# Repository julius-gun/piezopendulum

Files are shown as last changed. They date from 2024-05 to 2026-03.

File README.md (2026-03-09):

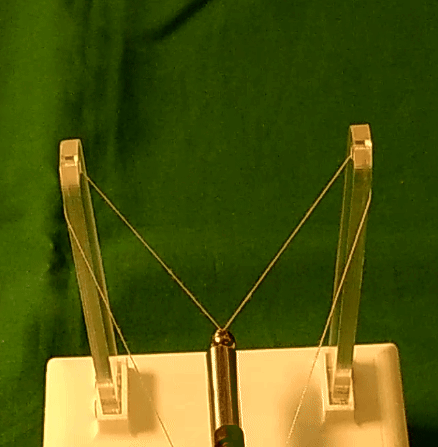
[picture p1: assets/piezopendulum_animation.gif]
[piezo animation]


**[Download the full video](https://github.com/julius-gun/piezopendulum/raw/refs/heads/main/assets/piezopendulum.mp4)**

---

# The Self-Sensing Piezoelectric Pendulum

### Vision: Rescuing a Legacy Demonstrator

This project revitalizes a classic 1993 piezoelectric pendulum, a key educational tool at the Technical University of Munich. The original, while brilliant, was facing obsolescence due to aging electronics and inaccessible Assembler software. The vision was to engineer a modern, robust, and user-friendly successor that preserves its core teaching value for the next generation of engineers.

---

### Watch it in Action

The new demonstrator successfully replicates all key operations of the original, including self-sensing impulse detection, launching a suspended ball, and achieving a precise, bounce-free catch upon its return.

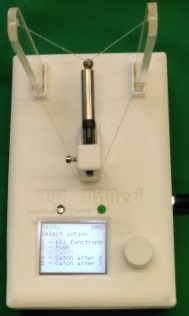
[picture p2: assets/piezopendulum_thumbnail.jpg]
Link to Video on GitHub


---

## Key Contributions & Features

*   **Complete Technological Overhaul:** Replaced 30-year-old electronics and Assembler code with a modern system based on a **Raspberry Pi Pico** and **C++**.
*   **Self-Sensing Actuation:** The piezo actuator itself detects the returning ball's impact, eliminating the need for external sensors.
*   **Precise Bounce-Free Catch:** The system discharges the piezo's energy at the right moment, causing the ball to "stick" to the actuator without bouncing.
*   **Integrated & Robust Design:** A compact, 3D-printed enclosure integrates the actuator and control unit, eliminating fragile external cables.
*   **Intuitive User Interface:** Simple rotary encoder and a clear LCD screen.

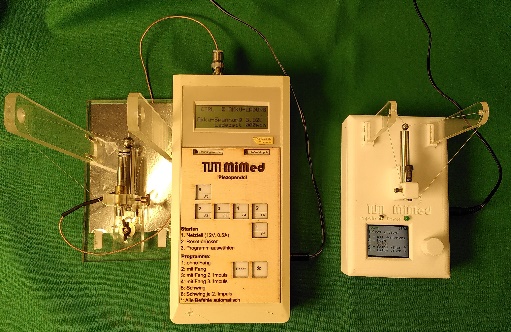
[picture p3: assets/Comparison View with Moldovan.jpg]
Comparison of the old and new pendulums


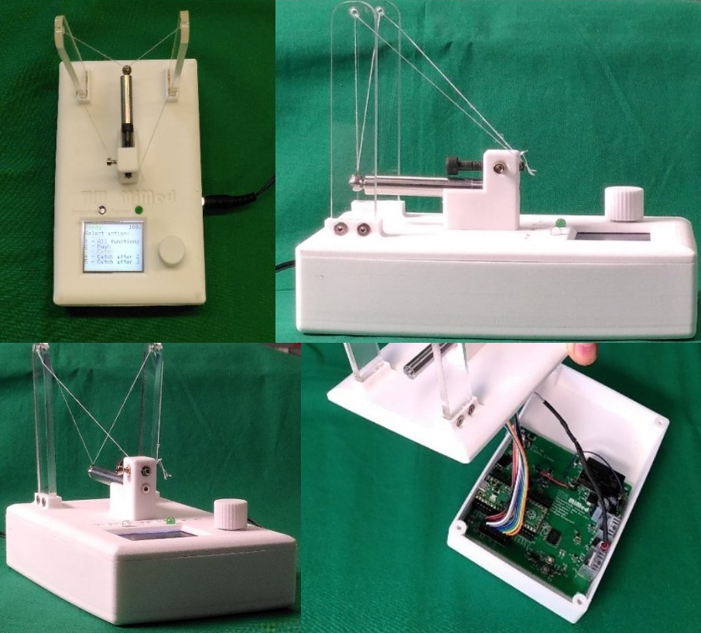
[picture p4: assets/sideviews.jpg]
Side views of the new pendulum


## Technical Breakdown

The project followed a clear modernization path:

1.  **Electronics Redesign:** A custom PCB was designed featuring a half-bridge configuration with fast-switching MOSFETs and a bootstrap gate driver to precisely control the high-voltage piezo actuator.
2.  **Intelligent Control:** A Raspberry Pi Pico runs the C++ firmware, handling user input, display updates, and the critical microsecond-level timing required for the bounce-free catch.
3.  **Physical Redesign:** The enclosure and actuator mount were designed in CAD and 3D printed, allowing for rapid prototyping and a compact, integrated final form.
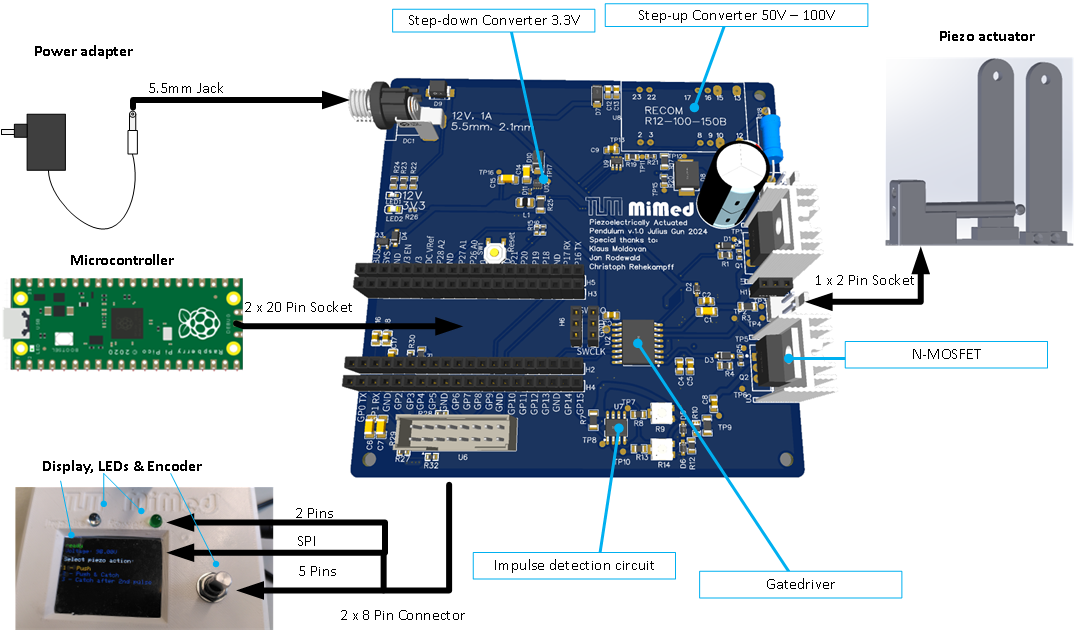
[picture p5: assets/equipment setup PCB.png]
Custom PCB with Raspberry Pi Pico

---

## Read the Full Thesis

For a complete technical deep-dive, including schematics, code, and design evaluation, you can access the full bachelor's thesis.

**[Download the Thesis PDF](self-sensing_piezoelectrically_actuated_pendulum_julius_gun.pdf)**

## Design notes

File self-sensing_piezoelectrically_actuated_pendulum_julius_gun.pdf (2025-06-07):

Technical University of Munich TUM School of Engineering and Design Institute of Micro Technology and Medical Device Technology (MIMED) Prof. Dr. rer. nat. Dipl.-Ing. Tim C. Lüth

Bachelor's Thesis

# Development of a Self-Sensing Piezoelectrically Actuated Pendulum

Julius Gun

Principal Investigator | Univ.-Prof. Dr. Tim C. Lüth Institute of Micro Technology and Medical Device Technology
Supervisor | Jan Rodewald, M. Sc. Institute of Micro Technology and Medical Device Technology
Beginning | 01.11.2023
Submission | 31.05.2024

Abstract

### Abstract

Klaus Moldovan's 1993 piezoelectric pendulum, a key demonstrator at the Technical University of Munich, faced obsolescence from aging electronics and Assembler software. I developed a modern successor, overhauling its technology while preserving its educational core. My goal was a robust, user-friendly demonstrator for engineering students.

My new pendulum retains the original's self-sensing capability. A linear piezoelectric actuator detects an approaching suspended ball without auxiliary sensors, propels it, and achieves a bounce-free catch upon return. This version uses a Raspberry Pi Pico microcontroller programmed in C++, a substantial upgrade.

The electronic redesign incorporates fast-switching MOSFETs with a bootstrap gate driver and a window comparator for impulse detection. I also created a compact, 3D-printed enclosure integrating the piezo actuator onto the control unit. This integration eliminates external cabling, enhancing robustness and aesthetics.

The resulting enhanced pendulum replicates all key operations of Moldovan’s device. A simplified user interface, with a single rotary encoder and push-button, makes the demonstrator intuitive. This project ensures a valuable, hands-on tool continues to teach piezoelectric phenomena effectively.

12 Keywords:

Self-Sensing Piezoelectrically Actuated Pendulum Smart piezoelectric actuator
Piezoelectric pendulum
Smart piezoelectric pendulum
Piezo pendulum
Self-sensing piezo actuator
Demonstrator of the piezoelectric effect and inverse piezoelectric effect Piezoelectric demonstration model
Piezoelectric damping
Piezoelectric feedback control
Actively damped piezoelectric system Piezoelectric actuation pendulum

Forword to Revised Version

### Forword to Revised Version

I have revised my submitted bachelor thesis, removing minor mistakes. I have inserted the updated version of code which has new functionalities and and now is optimized for a 4g ball. I also used Gemini 2.5 Pro Preview 05-06 for paraphrasing of my text so that the active voice is used.

If somebody wants to build a new piezo pendulum, then rather use a piezo actuator with a higher capacitance than the one used in this project and add a shunt resistor in front of it to avoid the resonance frequency (also see 2.6.1.2 Piezo Actuator, and 1.2.1.3 Characteristics of Piezoelectric Materials).

Also redesign the complete case, so that it is easier to open it (right now 4 screws need to be undone). Rather have the piezo connector outside the box and not inside so that an oscilloscope can easily be connected. It could even be desirable to have the piezo actuator mounted on a separate base, just like Moldovan 1993 did, if experiments are to be carried out.

For any questions regarding this pendulum, feel free to contact me.

Julius Gun, 07.06.2025

Acknowledgment

### Acknowledgment

This thesis would not be complete without acknowledging those who offered their expert guidance and support. My profound appreciation goes to Klaus Moldovan, originator of the 1993 piezo pendulum, for his readiness to assist through extensive correspondence, which proved critical to my study. My supervisor, Jan Rodewald, deserves special thanks for his continuous support and valuable counsel throughout this endeavor.
Gratitude is also owed to Dr. Franz Irlinger, who facilitated the acquisition of critical documents and my introduction to Klaus Moldovan. My respectful acknowledgment goes to Prof. Dr. Tim
C. Lüth, whose teachings ignited my fascination with electronics. The collaborative and welcoming environment provided by the team at MIMED has greatly enhanced my research experience. Acknowledgment is due to Christoph Rehekampff for his readiness to assist and his technical guidance with the electronic circuit.
Also, thanks to Andreas Haas from Physical Instruments (PI), Markus Wörl and Florian Schweidler.
Finally, I would like to thank my dear mother, Emma Weiß, for her support throughout all those years. You are wonderful.

Contents

### Contents

1. Introduction

### 1. Introduction

### 1.1 Application

Piezoelectric principles are pivotal in the "Mechatronic Device Technology" and "Microtechnical Sensors and Actuators" lectures at the Technical University of Munich. The piezoelectric demonstrator within this context provides students with an empirical understanding of the conversion of mechanical stress into electric charges and vice versa. Engaging with this demonstrator imparts valuable practical experience and technical knowledge essential for precise applications in advanced engineering sectors.

The application of piezoelectric effects in academic settings helps demonstrate and clarify advanced concepts. This leads to measurable educational outcomes in student engagement and understanding. This demonstrator transforms abstract textbook theories into a concrete example.

The practical deployment of piezoelectric devices spans a range of applications that benefit from high precision and quick responsiveness. Self-sensing piezoelectric ceramics offer an innovative method by combining actuation and sensation. This combination reduces physical dimensions and response time, significantly contributing to space-sensitive and finely tunable technologies.

In the medical field, the non-magnetic nature of piezo actuators is a major asset. These devices play a vital role in MRI scanners by enabling precise adjustments without interfering with the imaging process (Fischer et al., 2011; Wang et al., 2009) . Piezo technology is essential for administering accurate doses in medical pumps, like those for insulin. It is also used in ultrasonic surgical tools and diagnostic devices, such as ultrasonography transducers, where electromagnetic disturbance must be avoided (Li et al., 2009) . Additionally, these actuators facilitate precise fluid control in miniaturized lab-on-a-chip systems used for medical testing.

However, piezo actuators have a higher cost because of their sophisticated technology. They are also limited in their movement range, and their piezoelectric materials can be delicate, risking damage under high stress or if mishandled. Their operation typically requires high-voltage inputs, complicating the design. They are also sensitive to temperature changes, which could affect their functionality. Lastly, they exhibit varying levels of hysteresis and nonlinear behavior (Chopra and Sirohi, 2014, p. 154) . The perception of piezoelectric effects varies depending on the application.

Self-sensing piezoelectric ceramics combine action and sensing in one unit. These materials eliminate the need for separate sensors, offering both cost and space benefits (Muth et al., 1995,
p. 692) . Traditional sensors provide precision but often result in costlier and more cumbersome setups. These setups add excess wiring and demand more component room, as seen with encoders (Liseli et al., 2020, p. 2) . The compact design of self-sensing piezoelectric ceramics proves ideal for miniaturized systems and nano-positioning tasks where space is at a premium (see Liseli et al., 2020 for an overview).

1. Introduction

In some applications, the piezoelectric effect is invisible, while in others, it can be perceived visually, acoustically, or haptically. The piezo effect (a piezo actuator subjected to force generates voltage) is visually evident in the spark of a lighter, where applied pressure creates a visible, abrupt voltage between contacts (APC International, 2024) . Additionally, the inverse effect—a piezo actuator subjected to voltage generates force—is most notably observable in devices like high-precision stages. Here, piezo elements enable movement through the inverse piezoelectric effect. This same principle of voltage generation is used in scientific settings, like producing corona discharges in mass spectrometry (Wang et al., 2015) .

In practical applications, piezoelectric actuators exemplified in the Arburg Freeformer 3D printer's printhead demonstrate controlled, nuanced operations. These piezos produce an audible click as they dispense precise droplet formations at frequencies between 60 and 200 Hz, which is crucial for high-quality 3D printing (Arburg, 2024) .

Energy harvesting represents a silent yet impactful application of piezoelectric materials. Away from the audible clicks in 3D printing, these materials discretely capture electricity from vibrations, such as those from vehicles on roads, by embedding piezoelectric elements beneath the pavement (Kaur, 2016) .

The Technical University of Munich is pioneering piezoelectric energy harvesting, as represented in Figure 1. This prototype, a joint endeavor by Prof. Johann Plank and Prof. Xin Cheng, demonstrates the instant energy yield in Joules from pedestrian movement. Future improvements could lead to powering sensors and LEDs in high-traffic areas like bridges, subway stations, and nightclubs.

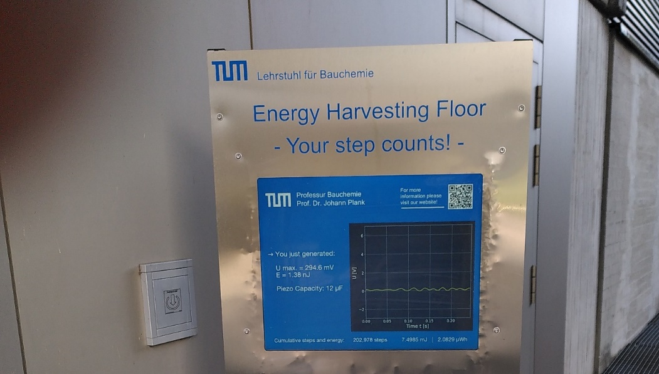
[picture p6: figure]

Figure 1 Energy harvesting floor at the entrance to the Chair for Construction Chemicals, Technical University of Munich.
In Rotterdam, the innovation of piezoelectric energy has been embraced in a dance club, which features a 38m²
area lined with piezoelectric tiles. This novel implementation results in a noteworthy 30% reduction in energy consumption, although the initial investment stood at $257,000 (Moussa et al., 2022, p. 4) .

1. Introduction

The bulk of this expenditure is often on the piezoceramic material, which in many cases consists of lead zirconate titanate (PZT). With ongoing research, more cost-effective lead-free piezoceramics may emerge on the market (Shrout and Zhang, 2007) . Seyfert et al., 2021 from the Technical University of Munich researched the use of piezoelectric PVDF film and its potential for energy harvesting. This study demonstrates the film's applicability in capturing energy from environmental mechanical forces.

Having reviewed some applications of piezoceramics, the next section examines the current state-of-the-art piezoelectric pendulum after some definitions.

### 1.2 State of the Art

This section delineates the current advancements in self-sensing piezoelectrically actuated pendulums. Piezoelectric devices operate through two fundamental mechanisms: the direct effect, where applied force is transformed into voltage detectable by specialized electronics, and the inverse effect, which involves expansion upon voltage application. Understanding these underlying principles is critical before discussing the current state-of-the-art piezoelectric pendulum.

The reader is assumed to have a foundational understanding of electronic concepts and formulae. Should further clarification or in-depth exploration be necessary, standard electronic textbooks are recommended as reference materials. Notable examples include the works of Tietze et al., 2016 and Horowitz and Hill, 2015 , which serve as comprehensive resources in the field.

### 1.2.1 Definition of Terms

The discovery of piezoelectric materials is attributed to French physicists Jacques and Pierre Curie in 1880. They unveiled the property of specific crystalline structures, like quartz, to generate an electric charge under mechanical stress. This bidirectional conversion capability between mechanical and electrical energies marks the cornerstone of piezoelectricity. The etymology of "piezoelectricity" is rooted in the Greek term 'piezein,' which translates to press, describing the materials' electric reaction to pressure.

### 1.2.1.1 The Piezoelectric Effect

When piezoelectric materials are subjected to stress, they produce a voltage. This is known as the piezoelectric effect. It is observed when a piezoelectric actuator, subjected to force F [N], generates voltage V [V], captured by equation (1). This shows how a piezoelectric actuator converts mechanical pressure (force per area) into an electrical signal (voltage). This is crucial for the device’s ability to detect a ball without other sensors, as I will discuss later.

V =

d33∗F
C

=

Q
C

(1)

V | Voltage | [V]
d33 | Piezoelectric module [m/V]
F | Force | [N]
C | Capacitance | [F]
Q | Electrical charge | [C]

1. Introduction

Here, the constant d33 [m/V] represents the longitudinal effect - the piezoelectric charge constant along the polarization axis of the piezoelectric material, while Q [C] is the electrical charge produced, C [F] is the capacitance of the piezoelectric material. My discussion focuses on a onedimensional scenario, considering the linear relationship between the force applied along the piezoelectric disc's polarization direction and the resulting electrical output.

The elongation ∆l/l in one dimension is proportional to the longitudinal effect d33 along the polarization axis of the piezoelectric material, see equation (2). This is important because it mathematically expresses the direct proportionality between the mechanical stress σ(which is force per area) experienced by the device and the electric field/response ε. This relationship further underpins the actuator's ability to convert electrical signals into mechanical pressure. Thus, a force of a ball on an actuator produces an electrical signal and vice versa, validating the piezoelectric behaviour explored in this research.

∆l
l

=

σ∗1
E

+d33∗ε

(2)

∆l/l | elongation | [-]
σ | Mechanical stress | [N/m² ]
E | Young's modulus | [N/m² ]
d33 | Piezoelectric module [m/V]
ε | Electric field | [V/m]

### 1.2.1.2 Inverse Piezoelectric Effect

Conversely, when a voltage is introduced to the piezoelectric material, its shape alters by extending in length ∆l. This is called the inverse piezoelectric effect.

### 1.2.1.3 Characteristics of Piezoelectric Materials

When examining piezoceramics, it is critical to understand that the absorbable and releasable energy Wa, measured in joules (J), is calculated by formula:

W a=

1
2

∗Cp

∗V p

2

(3)

The capacitance and voltage range determine the energy a piezo can absorb and release; therefore, this is an important consideration when selecting a piezo actuator. Most notably, the energy quadruples when the voltage Vp is doubled.

Characterizing the piezoelectric device electrostatically, one can conceptualize it as a capacitive entity. The capacitance Cp [F] of such a device is quantitatively defined by equation (4),

Cp=

ε0∗εr∗A∗n
h

=

ε0∗εr∗π∗r

2∗n
h

(4)

1. Introduction

where ε0 is the electrostatic constant, εr
is the relative permittivity of the piezoelectric material, A is the area of the individual ceramic disc, r is the radius of the disc, n denotes the total number of piezoelectric ceramic discs in the stack, and h is the distance between the piezoceramic discs. From equations (3) and (4) it follows that the absorbable energy is proportional to the capacitance Cp. Notably, the capacitance is directly proportional to the square of the actuator's radius and to the number of discs, which accounts for the actuator's dimensional properties – width and length, respectively.

The function of the piezoelectric pendulum, which uses a linear piezo actuator, is the focus of my investigation. Figure 2 portrays the process of energizing the piezoelectric material by applying voltage through wires, resulting in its expansion by a length of ∆l; the material contracts to its original size upon removal of the voltage. In the depiction, the left side shows the connection to the voltage source and the grounding at the other end. Typically, the piezoelectric stack is composed of numerous layers of ceramic, often using a material known as lead zirconate titanate (PZT).

Figure 2 Structure and contacting of a stacked piezo actuator (Image used with kind permission from PI Ceramic GmbH, available at https://www.piceramic.com/en/expertise/piezo-technology/properties-piezo-actuators/electricaloperation (https://www.piceramic.com/en/expertise/piezo-technology/properties-piezo-actuators/electrical-operation) [Accessed 14 May 2024])

Figure 3 shows a sectional view of a linear piezo actuator. Its multilayered structure increases its capacitance according to equation (4). A hardened tip prevents damage to the actuator's head. For secure attachment, the mounting plate has a thread to enable screwing it into position.

Figure 3 Linear piezoelectric actuator in cut view. The ball hits the hardened head on the right side. (Image used with kind permission from Klaus Moldovan (Muth et al., 1995, p. 699) )

1. Introduction

As depicted in Figure 4, the piezo actuator's behavior can be likened to that of a capacitor (Cp). It is critical to recognize that the piezo and parasitic resistance form a low-pass filter, with a cutoff frequency fp given by equation 5:

f

p=

1
2 π RpCp

(5)

Figure 4 Schematic of parasitic resistance and capacitance of piezo actuator, forming a low-pass filter.
A design must consider the piezoelectric actuator's capacitance and the parasitic resistance. In a numerical simulation of a piezo ceramic at impact by a steel ball by Schweidler, 2004, p. 42 , post-impact oscillations of the piezoceramic endure for approximately 5ms. This phenomenon is visually represented in Figure 5, capturing the attenuated response past the moment of impact. The actuator is vibrating, as it is subjected to both tensile and compressive stress in a fastreciprocating manner.

The frequency with which the piezo oscillates in this process is dependent on equation (5). It would be desirable to have a cutoff frequency f3db

1
from below the resonance frequency to avoid destroying the piezo. Otherwise, it could oscillate so severely at its resonance frequency that the many layers of glued piezoceramic would separate (Moldovan, 1994a, p. 22) , effectively destroying the device. Achieving a cutoff frequency below the resonance frequency can be done by using a piezo with a high capacitance Cpor by increasing Rp, for example, by adding a resistor in series with the piezo.

1
The cutoff frequency f3db is the point of a filter where the attenuation of the signal is reduced to 0.707 times the maximum gain.

1. Introduction

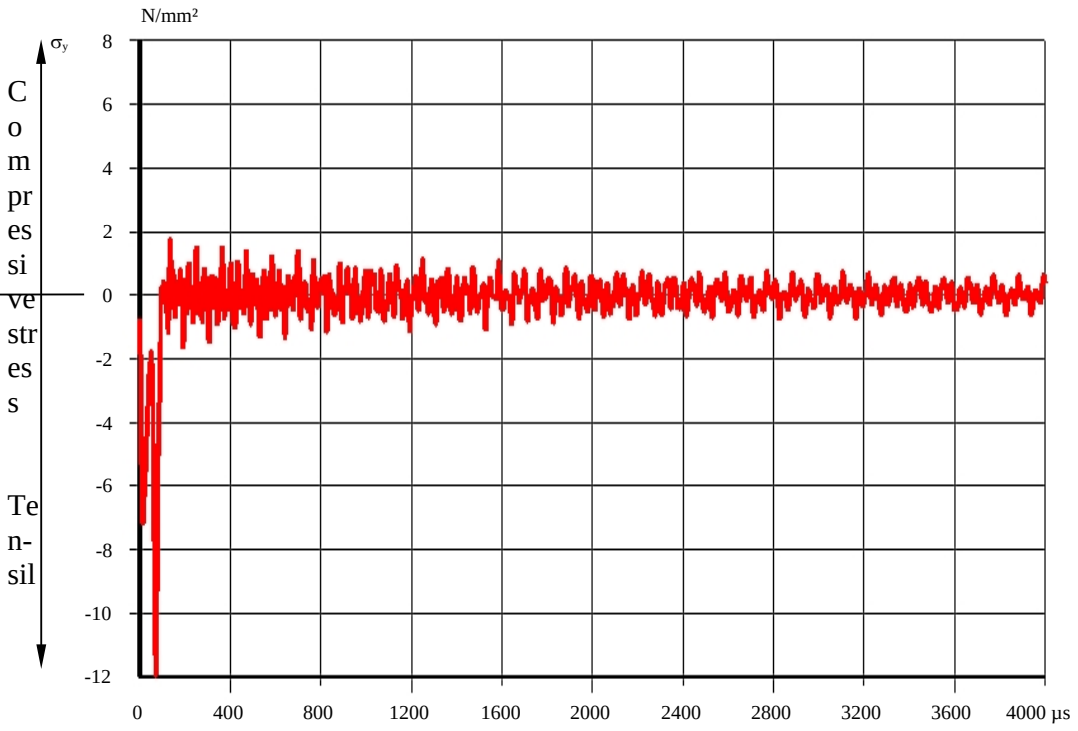
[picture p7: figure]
N/mm²; C o m pr es si ve str es s; Te n- sil

Figure 5 Simulated stress of the piezo actuator on in contact with a ball in the axial direction (Image used with kind permission from Florian Schweidler (Schweidler, 2004, p. 42))

The voltage across the piezo is:

V p=Rp

∗I

(6)

where Rp is the parasitic resistance before the piezo and I is the current across it.

The dynamic voltage at charging of the piezo V p

(t) when charging the piezo is given by equation (7), and when discharging by equation (8), where t represents the time. Figure 6 shows a plot with exemplary values. This resemblance to capacitor voltage characteristics is expected because the piezoelectric device has its own capacitance, as per equation (4). Upon activation, the piezoelectric device's voltage rises to a peak value V, and upon deactivation, it decreases back to 0 volts.

V p

(t)=V∗e

−t
Rp∗Cp

(7)

V p

(t)=V∗(1−e
−t

Rp∗Cp )

(8)

1. Introduction

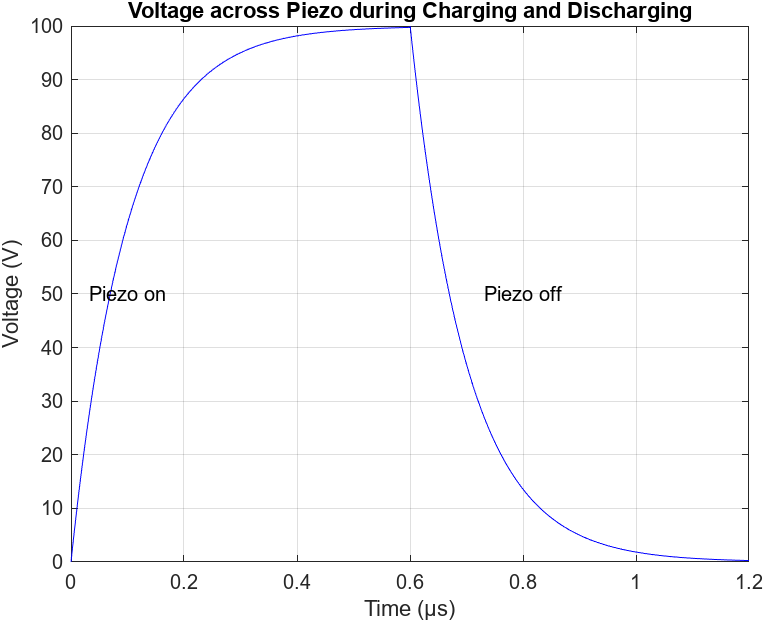
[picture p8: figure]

Figure 6 Voltage across piezo during charging and discharging with exemplary values.

### 1.2.1.4 Test Setup

Figure 7 shows a schematic of the demonstrator's test setup, consisting of a piezo actuator and pendulum. A ball with a mass mb is suspended by a string from above. Gravity is signified by g (9.81 m/s²
), h is the height, and φ is the angle at which the ball is at the moment. When the piezo is turned on, it charges. Consequently, electrical energy (equation (3)) is turned into kinetic energy (equation (9)). The ball is shot away with a velocity vb and flies to a certain height, h. There, the potential energy is at a maximum, as denoted in equation (10).

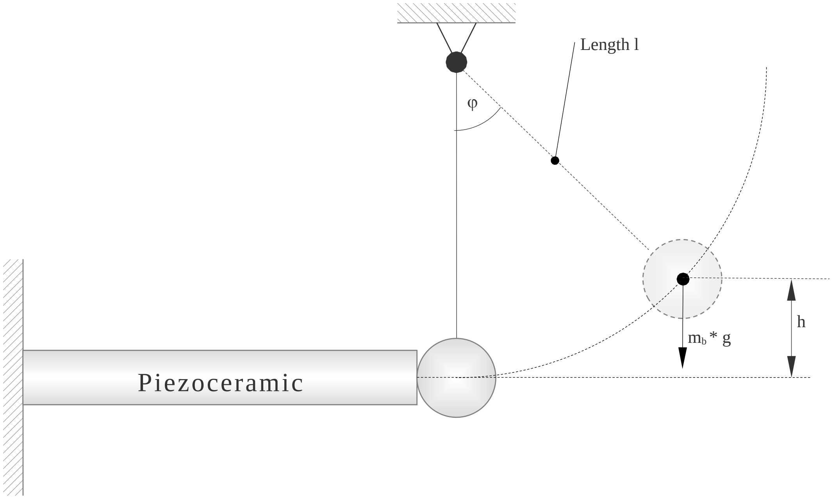
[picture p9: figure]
Length l; Piezoceramic

Figure 7 Schematic of piezo actuator and pendulum (Image used with kind permission from Florian Schweidler (Schweidler, 2004, p. 23))

At the lowest point (h = 0m) the kinetic energy Ek
is highest and is given by equation (9). Ek=

1
2

∗mb∗vb

2 | (9)

The potential energy Ep is is given by equation 10.:

1. Introduction
Ep=mb∗g∗h | (10)
In an ideal setting, Ep equals according to energy conservation principles, and so the resulting velocity vb is given by:
vb=√2∗g∗h | (11)

This equation allows calculation of the ball's velocity at its lowest point, just before contacting the actuator, simply by knowing the height to which it was shot. In this ideal setting, the velocity with which the ball is shot is approximately the same as the final velocity when it hits the piezo again. The consistency in initial and return velocities is essential for determining the correct delay for discharging the piezo's stored energy. This allows for a bounce-free catch of the ball, which I will discuss in the next section.

### 1.2.1.5 Bounce-free Catching of a Ball

For the ball to adhere instantly, the actuator must absorb all the collision's energy. As the ball hits the expanded ceramic material, it applies a compressive force, altering the electrical charge and causing a detectable voltage shift. The electronics of the system then release the energy from the ceramic at the precise moment to ensure the ball remains in place (Muth et al., 1995,
p. 692) . Because the initial velocity is approximately the same as the final velocity when the ball returns, only the correct time delay to discharge the piezo needs to be found.

Figure 8 shows the force-time curve of a ball on impact with the piezo pendulum with exemplary values (Schweidler, 2004, p. 12) . The sketches above the curve show the position of the ball at each point in time. Fb(t) represents the curve of the force of the ball over time. At t1 the ball hits the piezo and starts to compress. Then the force rises until it reaches its maximum force Fmax at t2 when the ball is in the most compressed state. After this, the force falls again, reaching the bottom end at t3 when the ball leaves the actuator again and flies off (this is not

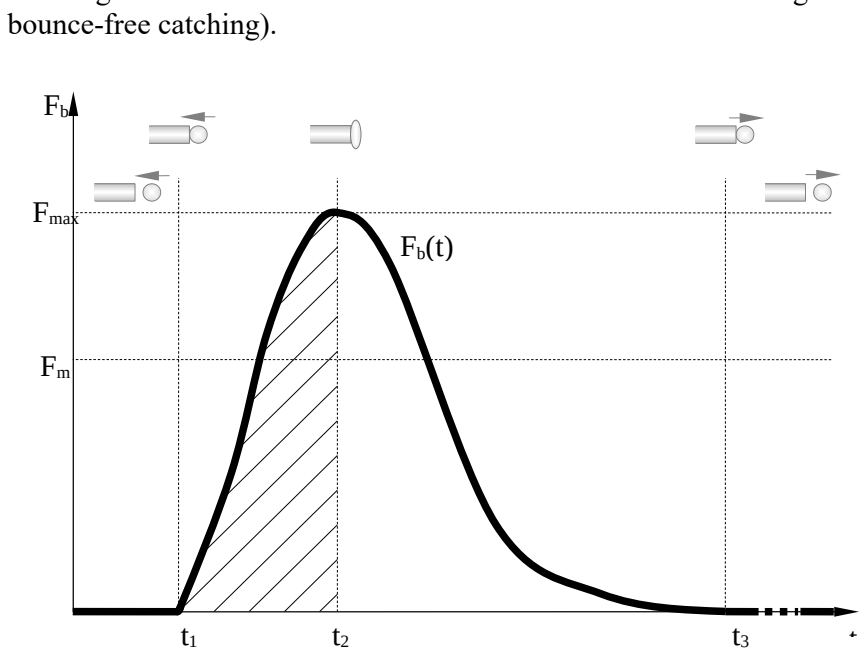
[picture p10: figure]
bounce-free catching).; Fmax

Figure 8 The characteristic curve of the force Fb during the first contact of the ball with the piezoceramic. The sketches above the curve show the position of the ball at each point in time. (Image used with kind permission from Florian Schweidler (Schweidler, 2004, p. 12))

1. Introduction

The average force Fm [N] over the impact duration is equal to:

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
Fb∗dt=

1
t

2−t
1

( p2−p1)

(12)

The momentum p [N/s]is defined as:

p=mb∗vb

(13)

The impulse ∆ p[N * s], the change in an object's momentum when a force is applied over time, is the area under the curve in Figure 8 and is given by the following equation:

∆ p=p2−p1=mb∗( v2−v1

)

(14)

When the piezoelectric actuator in the demonstrator detects the incoming ball, its task is to generate enough counter-impulse to stop the ball, effectively making the final momentum of the ball zero and, therefore, preventing it from bouncing off. The piezoelectric actuator must produce a force for a specific duration to create a counter-impulse equal and opposite to the ball's momentum. It achieves this by discharging the piezo at the correct moment. This effect permits a ball to "stick" to the actuator upon impact without bouncing back, as noted by Muth et al., 1995, p. 692 . It gives the illusion that the ball is magnetically attached to the actuator.

The timing of this force is critical - if released too late or too early, the desired effect of "sticking" will not be achieved. This delay time can be determined experimentally. Alternatively, a sophisticated algorithm could be developed. Accurate timing for a bounce-free catch may be determined through real-time voltage monitoring at the point of contact. This requires a calculation that accounts for initial voltage, ball mass, electronic response time, and the piezoelectric material's delay properties.

### 1.2.2 The Piezo Pendulum Engineered by Klaus Moldovan

Currently, the piezo pendulum developed by Klaus Moldovan in 1993 at the Technical University of Munich represents the state of the art for academic demonstrations (Moldovan, 1993) . No other similar piezo pendulum demonstrator is known to the author. Figure 9 depicts the design of Moldovan's device: A ball is attached to a string (1) so that the tip of the piezo actuator (2) touches it when the ball is at its lowest point. The piezo is screwed to a piezo holder (3), which itself is connected to the piezo base (4). Cable connection (5) to the control unit permit the piezo to be energized. The control unit, incl. display (6) and buttons (7), enable the user to choose functions. Extensive documentation of the pendulum by Moldovan allows for an in-depth understanding of the system (Moldovan, 1994a, 1994b, 1994c) .

1. Introduction

Figure 9 Representation of the piezo pendulum engineered by Klaus Moldovan. Ball on a string (1), piezo actuator (2), piezo holder (3), piezo base (4), cable connection to the control unit (5), control unit incl. display (6) and buttons (7)
Figure 10 a) shows a photo of the pendulum developed by Moldovan. A wooden panel was added later for simplicity. The control unit without the wooden panel is shown in Figure 10 b). There are 16 buttons to operate the unit.

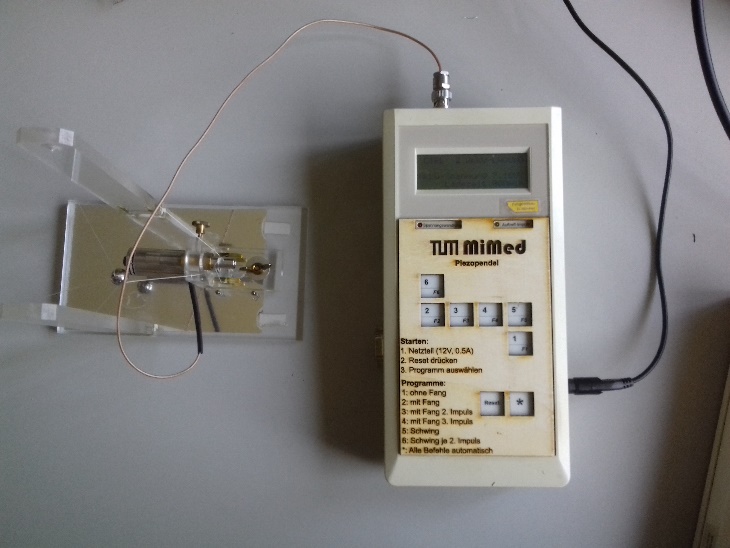
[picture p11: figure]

a) b)

Control Unit

Figure 11 and Figure 12 provide insight into the innovative use of power electronics. Moldovan’s choice to implement a flyback converter for piezo voltage management and two forward converters for controlling the two Metal Oxide Field Effect Transistors (MOSFETs)—a type of switch—is of particular interest. These three transformers were custom-made for this purpose (Moldovan, 1993, pp. 29–34) . This level of craftsmanship underscores the customdesigned nature of the pendulum's electronic system. Additionally, the incorporation of a rechargeable battery alongside the 12V power supply enhanced the device's portability.

Figure 10 a) Piezo pendulum engineered by Klaus Moldovan with later wooden panel modification Right: Control of the piezo pendulum engineered by Klaus Moldovan without wooden panel

1. Introduction

A full explanation of the symbols displayed and terms being used can be found in the referenced materials or standard electronic textbooks, such as those provided by Tietze et al., 2016 and Horowitz and Hill, 2015 .

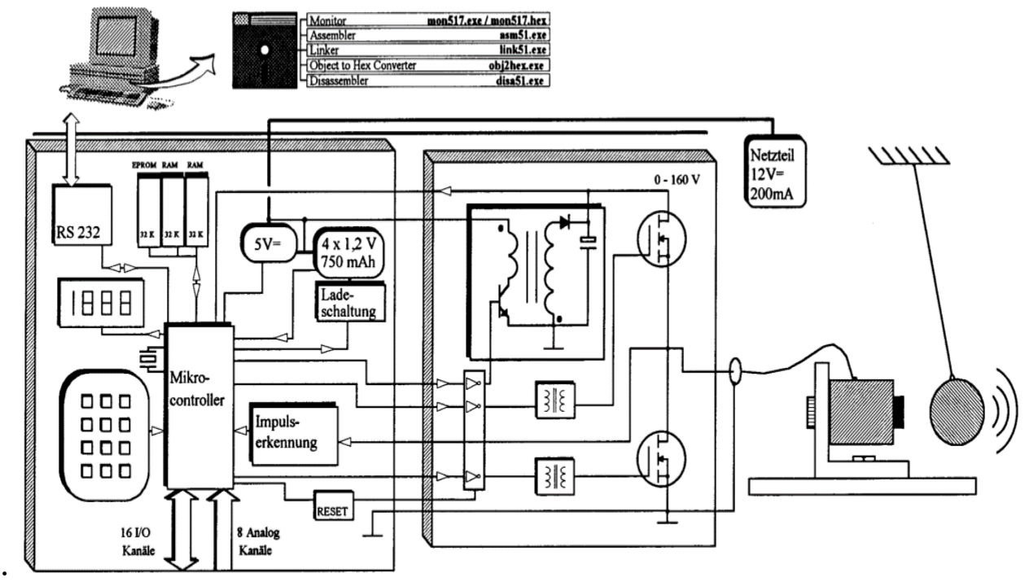
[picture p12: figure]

Figure 11 Basic view of the parts in the piezo pendulum engineered by Klaus Moldovan (Image used with kind permission from Klaus Moldovan (Moldovan, 1993, p. 8) )
Figure 12 offers a more detailed view of the hardware configuration within the piezo pendulum engineered by Klaus Moldovan. Notably, Moldovan's design incorporates two MOSFETs connected in parallel.This connection increases the maximum current the piezo receives. He also implemented a hardware oscillator and counter circuit crucial for controlling operational delay times. This configuration ensures exact timing for the pendulum ball's launch and capture, which is pivotal for system accuracy, as discussed in section 1.2.1.5. Such precision enables timing adjustments to within 55.6 nanoseconds (Moldovan, 1994a, p. 9) .

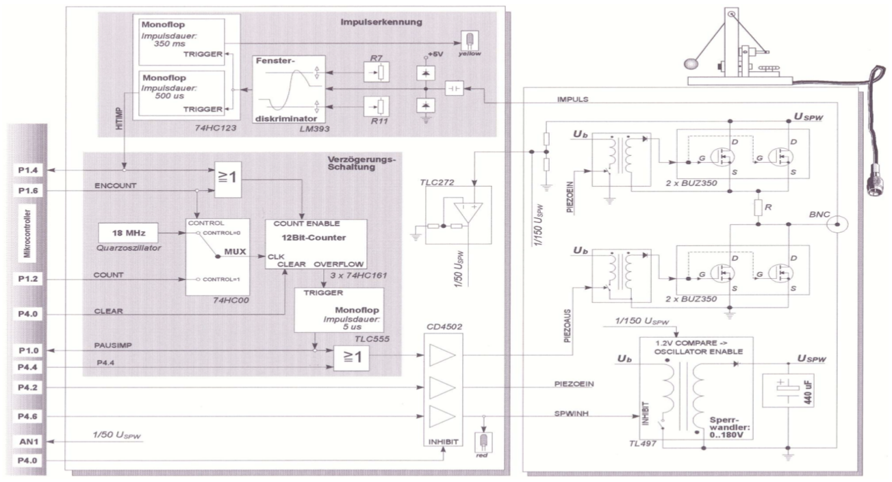
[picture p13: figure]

Figure 12 Hardware structure of the piezo pendulum engineered by Klaus Moldovan (Image used with kind permission from Klaus Moldovan (Moldovan, 1994a, p. 3) )

1. Introduction

Functions of the Control Unit of Moldovan
The control unit's functions, listed from 1 to 7, illustrate the system’s versatility. The system was carefully designed to store parameters in an electrically erasable programmable read-only memory (EEPROM).

The functions of the control unit are:

1. Shoot: Launches the pendulum ball.
2. Shoot and Catch after First Impulse: Catches the ball as it returns.
3. Shoot and Catch after Second Impulse: Captures the ball after a second impulse.
4. Shoot and Catch after Third Impulse: Secures the ball post-third impulse.
5. Resonance: Propels the ball upon immediate impulse detection.
6. Resonance after Second Impulse: Projects the ball after the second impulse is detected.
7. All Functions: Cycles through all modes sequentially.

Also, there is a mode of simultaneous operation. When linked via RS232, two control units can operate two pendulums in alternation.

A helper function in the pendulum assists in finding optimal delays, as shown in Figure 13. The correct delay for discharging the piezo is very important for a bounce-free catch, as discussed in the section 1.2.1.4. Each catch mode necessitates specific delays; voltage changes require delay recalibration for all functions, and this helper function speeds up the process. The ball is shot periodically in this mode. The delay time to discharge the piezo is incremented or decremented in steps according to the user input. It is not fully automatic; it needs operator confirmation of ball catch but refines delays in steps to enhance performance.

Figure 13 Automatic time delay configuration of the piezo pendulum engineered by Klaus Moldovan (Image used with kind permission from Klaus Moldovan (Moldovan, 1994a, p. 11) )
The remarkable durability of Klaus Moldovan’s pendulum, with an operational lifespan of 30 years, can likely be attributed to the strategic incorporation of high-quality digital components. Analog components, which are often more susceptible to inaccuracies, were judiciously employed only when absolutely essential.

1. Introduction

### 1.2.3 Research about Piezoelectricity

Having examined the state-of-the-art pedagogic demonstrator, attention now turns to contemporary research in piezoelectricity and the concept of self-sensing actuators powered by piezoelectricity. A self-sensing piezo device uses piezoelectric ceramics for both actuation and detection. This eliminates the need for an external sensor to determine, for example, position (Dosch et al., 1992, p. 167) . Expanding the knowledge on piezoelectric materials, Dosch et al., 1992 showcased that a piezoelectric element could simultaneously serve as an actuator and sensor. They proposed this method as an efficient vibration damping mechanism in a cantilever beam. This integration reportedly decreased the system's stabilization time by a factor of ten compared to systems not using piezoelectric technology.

In another study, it was shown that it is possible to recover the energy stored in a linear piezo actuator during the discharge phase and, with this, to estimate the piezo position with an error of less than 5% (Chiaberge et al., 2009, p. 8) . The system was developed for fuel injection in the cylinder combustion chamber.

Despite their typically limited range of motion, piezo actuators' displacement can be significantly augmented through the application of elevated voltages or lever amplification mechanisms. Li et al., 2024, p. 55 reported achieving a 558.3 µm displacement using a lever mechanism at 150V, although the resulting motion exhibits nonlinearity. To address this, the researchers devised a control algorithm tailored to the multistage amplifying mechanism's complex hysteresis behaviour.

At the Technical University of Munich, significant research on piezoelectric ceramics has been carried out within the Institute of Microtechnology and Medical Device Technology (MIMED), as well as its predecessor, the Institute of Microfabrication Technology.

For example, in the realm of printing technology, Rumschoettel et al. crafted a predictive model for a piezoelectric drop-on-demand (DoD) printhead (Rumschoettel et al., 2014; Rumschoettel et al., 2015) . Their model forecasts key droplet attributes, facilitating swifter printing speeds and enhanced precision in droplet placement. Furthermore, Kagerer developed a piezo inkjet drop-on-demand experimentation platform manufactured with rapid prototyping techniques. (Kagerer et al., 2012) . He further showed a cheap and fast way to make unique models of piezoelectrically operated microdroplet generators (Kagerer et al., 2012; Kagerer, 2016) .

1. Introduction

### 1.2.4 Research about Piezoelectrically Actuated Pendulums

Heider, 1976 , demonstrated the effective use of piezoceramics in dot matrix printers. His research focused on the capture process of a rapidly activated print element. Heider's work on dot matrix printers is a foundational study of piezoceramics handling fast, successive impacts. This process parallels the ball being stopped without rebounding in the model I developed. For visual reference, Figure 14 shows one of Heider's experimental setups Figure 14 (Heider, 1976,
p. 15) , which resembles my demonstrator's setup shown in Figure 7.

Figure 14 Experimental setup of the piezo pendulum according to Heider (Heider, 1976, p. 15) (Image used with kind permission from Florian Schweidler (Schweidler, 2004, p. 5) ).
To validate the findings by Heider, 1976 , Florian Schweidler (2004) conducted numerical simulations to analyze stress within a piezoceramic pendulum, using the finite element method (FEM). Through ANSYS, a software dedicated to engineering simulations, he mapped the pressure wave propagation within the piezoceramic upon collision with a steel ball. Figure 15 in his publication presents a three-dimensional model depicting the sizes of a piezoceramic (left) and a steel ball (right) during impact.

Figure 15 Three-dimensional representation of piezoceramic(left) and steel ball (right) in the correct size ratio (Image used with kind permission from Florian Schweidler (Schweidler, 2004, p. 28) )
Figure 16 displays one of Schweidler’s simulation that captures the stress experienced by the piezoceramic at the moment of impact with the steel ball. At this instant, the compressive stress peaks at the piezoceramic's free end, located on the right side (illustrated in red).

Figure 16 Two-dimensional representation of stress in the piezoceramic at impact of steel ball. The compressive stress at the free end (right) reaches its first maximum. The ball is (approximately) stationary in this moment. (Image used with kind permission from Florian Schweidler (Schweidler, 2004, p. 32) )
The stress curves observed from Schweidler's analysis show a considerable match with the experimental stress curves Heider demonstrated in 1976 . This comparison offers a comprehensive examination of the stress response in a piezoceramic subjected to impact by a steel ball. The congruence between the simulated stress distribution and Heider's data strengthens the understanding of the piezoelectric effect in dynamic situations. Together, the analyses affirm the foundational design concepts of the device and underscore the viability of piezoelectric applications in practical settings.

1. Introduction

Muth et al., 1995 further used the same experimental setup in Figure 7 to to evaluate the ball’s velocity in correlation with its mass(Figure 17 a)). They deduced the velocity from the highest point of the ball's post-launch trajectory, using equation (11). Measuring the electrical energy, they calculated the electromechanical efficiency as a function of the steel ball mass (Figure 17 b)). Most notably, the most efficient ball in their setup weighs approximately 24g, achieving a small electromechanical efficiency of 4.8%, while a 3g ball had an efficiency of 1.8%. Leveraging insights into bounce-free catching of the ball, the researchers explored the use of piezo actuators in active damping within optical scanners (Muth et al., 1995, p. 701) .

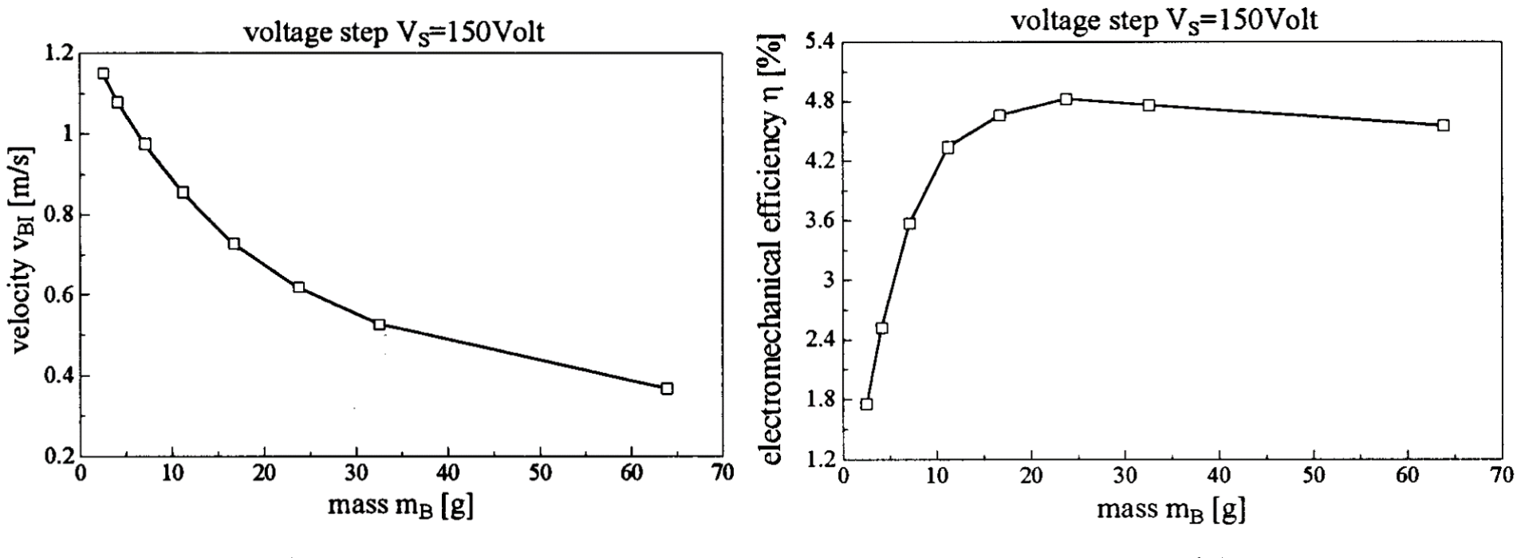
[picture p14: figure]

a) b)
Figure 17 a) Velocity vBI of the steel ball as a function of its mass mB (Image used with kind permission from Klaus Moldovan (Muth et al., 1995, p. 698) ); b) Electromechanical efficiency η as a function of the steel ball mass mB (Image used with kind permission from Klaus Moldovan (Muth et al., 1995, p. 698) )

### 1.3 Disadvantages of the State of the Art

With three decades of service, the pendulum is approaching the end of its operational lifespan. Given its age, mechanical and electrical malfunctions are increasingly likely. Future repairs may be challenging because of obsolete parts or design complexity. Moreover, the existing apparatus presents logistical challenges: As illustrated in Figure 9, the piezo actuator (2) is connected to the controller (6) via a cable (5), creating a vulnerability. This design leaves the system at risk of cable damage, which could easily occur through accidental mishandling or neglect.

The original documentation for the pendulum was misplaced for a period, presenting a hurdle for new operators unfamiliar with the system. To mitigate this challenge, a wooden panel was added to the control unit. Illustrated in Figure 10 a), this panel distinctly identifies each button and provides direct instructions, improving user navigation and simplifying the operation process. Nonetheless, users must manually initiate the reset button upon system startup, a step that persists despite enhancements.

Additionally, the software for Klaus Moldovan's piezo pendulum was written in Assembler—a common choice in 1993 because few programming languages were available for microcontroller development. While Assembler is a fast-executing language, its low-level nature, akin to machine code, renders code modifications quite challenging when compared to more contemporary languages. The software development was not only complex and time-consuming but also demanded specialized expertise. Each alteration required opening the device, physically removing the EPROM chip, and reprogramming it with an EPROM programmer. This labor-intensive procedure added a layer of difficulty to maintaining and updating the pendulum's functionalities.

1. Introduction

Besides the difficulty of changing the software, future failures are possible, and repairs would be complicated.

Figure 18 reveals the interior of the piezo pendulum engineered by Klaus Moldovan. While many components are socketed for easy replacement, a significant obstacle exists: the discontinuation of certain components. For example, the Infineon BUZ350 MOSFET, integral to the device, is no longer in production, complicating maintenance and potentially rendering future repairs infeasible or at best, problematic. Contemporary components may share the same form factor, and with diligent searching, suitable replacements might be found. However, this does not guarantee ease of repair given the obsolescence of these essential parts.

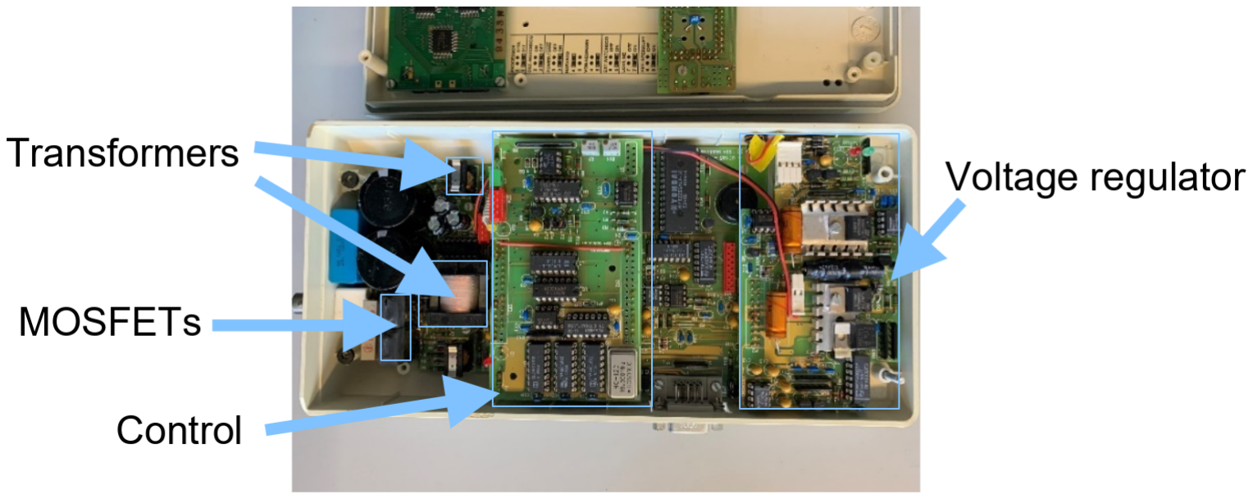
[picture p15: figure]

Figure 18 Piezo control of Moldovan from the inside

2. Methodology

### 2. Methodology

### 2.1 Problem Definition

In this thesis, I aim to create an improved piezoelectric pendulum for educational demonstrations at Munich's Technical University, particularly for courses on Mechatronic Device Technology and Microtechnical Sensors and Actuators. The objective is to upgrade the pendulum's electronics and replace Assembler with a user-friendly programming language, without losing essential features. Additionally, the project intends to simplify the operational process by reducing the number of steps required for activation of functions. Finally, I will evaluate whether the new design maintains the foundational features of Klaus Moldovan's piezo pendulum.

### 2.2 Expected Advantages and Functions of the Solution

Modern programming languages like C++ or Python, with their more accessible syntax and rich libraries, are expected to offer significant benefits in the development and maintenance of the pendulum system, ensuring its longevity and adaptability. Adopting such languages for programming the pendulum system would also allow for more agile responses to changes and potential issues, because the software is easier to update.

Interaction with this demonstrator will afford students practical insight. Their academic growth will intersect with the application of piezoelectricity in precision engineering, medical technology, and microsystems. The adoption of this application-oriented educational method enhances the learning experience significantly. It also imparts crucial skills, preparing students to emerge as visionary engineers, innovators, and inventors in the ever-evolving domains of mechatronics and microtechnology.

The pendulum's upgraded design aims for enhanced usability, functionality, and simple maintenance. It also supports long-term financial viability by reducing the need for specialized expertise or equipment for upkeep.

### 2.3 Structure of the Solution

Figure 19 a) shows a basic diagram of my novel pendulum system, capturing its essential innovation. It serves as an initial visual representation of how the actuator interacts with the controller. A ball is suspended from a cord (1), and a piezo actuator (2) is capable of rapidly launching and catching the ball. This actuator is mounted on a holder (3) and its cable is invisibly connected to the control unit (4). This design leaves the system not at risk of cable damage, which could easily occur through accidental mishandling or neglect. Finally, an LCD display (5) informs the user with relevant data, e.g. of the available functions, and a push-button encoder (6) allows user interaction.

The GUI uses a minimalist design, promoting an intuitive interface with a single encoder and a pushbutton. Such a configuration streamlines interaction by focusing on simplicity and mitigating potential confusion from excess controls. The user-friendly design follows Norman's (2013) principles, advocating for simplicity, reduced cognitive load, and easily reachable functions. Such adherence ensures efficient, precise interaction without requiring extensive guidance.

The GUI forgoes an On-switch, activating instantly with power cord connection. Functions are readily accessible, with navigation via encoder and selection using the button, prioritizing straightforward operation. Figure 19 b) provides a basic visual of the menu. A green text display indicates the device is ready. The voltage is shown in blue on the right.

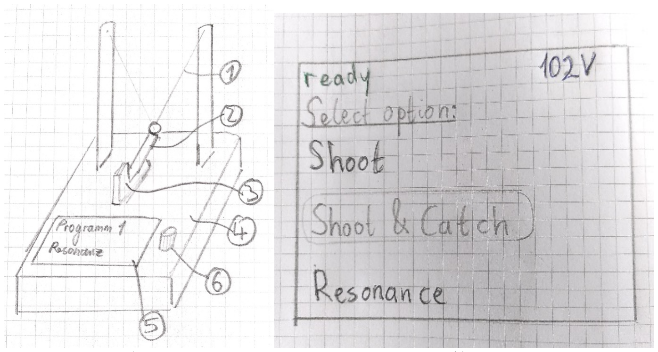
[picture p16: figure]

a) b)
Figure 19 a) Concept of new pendulum. Ball on string (1), piezo actuator (2), piezo holder (3), piezo control unit(4), LCD display (5), encoder with push-functionality (6); b)Basic structure of the GUI

### 2.4 Process of the Solution

Figure 20 clarifies the interaction between the control unit, the actuator, and sensors. The control unit uses the piezo as both a sensor and an actuator. The process involves the interaction with the ball. When the control unit charges the piezo, the ball is pushed away or caught. This is the piezo acting as an actuator. Once a returning ball touches the piezo, it alters its electric charge and causes a voltage shift, which is then detected by the control unit. Users can view data and system commands on a display and manipulate the system by selecting options via an encoder with inherent push capability.

Figure 20 Structure of communication between control unit and the actuator and sensors
Figure 21 presents a streamlined flowchart detailing user interactions within the menu framework. Upon device initialization, a menu with multiple selections appears. A user's choice dictates the program's subsequent operation, including options such as "Play all functions," "Push," "Push and Catch after n Bounces" (with n being 1, 2, or 3), and "Resonance after n bounces." After completing a selected activity, the user can choose another operation; however, this subsequent selection process is not depicted because of spatial constraints.

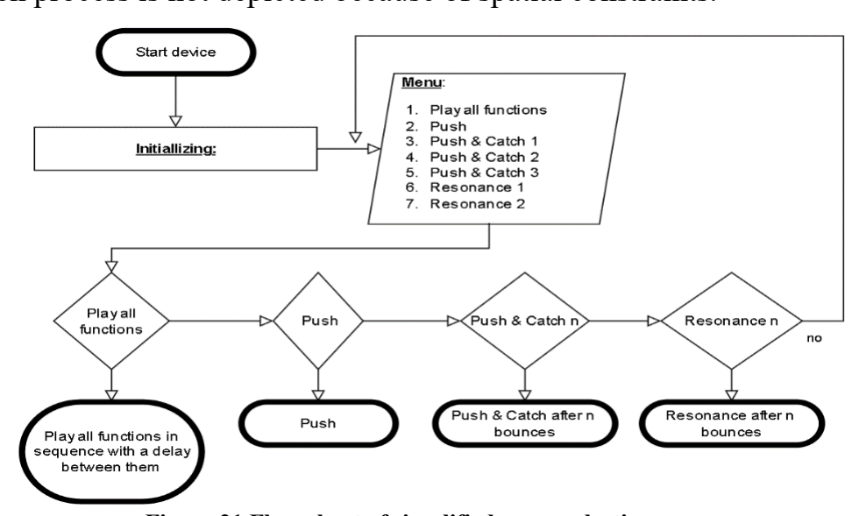
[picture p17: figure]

Figure 21 Flow chart of simplified menu selection process
Figure 22 shows the process of the simplified program for catching a ball bounce-free. Once started, the device needs to initialize. Then it is idle. If the user selects the function for shooting and catching the ball in the menu, it is executed. The piezo charges, the ball flies away and returns. Once the ball hits the piezo, it is detected. After a catching delay (explained in the section 1.2.1.4), the piezo discharges, and the ball is caught bounce-free. Then the device is idle again, until the user selects the function again.

Figure 22 Activity diagram of a simplified program for catching a ball bounce-free

### 2.5 Delimitations of the Solution

The proposed solution is distinguished from the state-of-the-art pendulum by several distinct features. Specifically, it will undergo a full renovation that includes the integration of modern electronics and the adoption of a new microcontroller. Additionally, it will use a comprehensive programming language and feature a straightforward GUI design, distinguishing it from the existing state-of-the-art pendulum.

### 2.6 Laboratory and Equipment Setup

Section 2.6 outlines the basic components and structures of my lab setup so that others can accurately replicate it. This section explains the rationale behind selecting specific components and methods used in my solution, briefly touching on critical decision-making processes. Detailed descriptions of the software will not be provided, but all algorithms critical to the operation will be briefly outlined, along with their relevant parameters.

Electrical Hazard from Experimental Setup

The principal risk associated with this research is potential electric shock from the current used to power the piezoelectric actuator. It is of paramount importance to exercise caution when using tools such as oscilloscopes or multimeters on powered circuits, as contact with high-voltage components can result in injury. It is advisable to work in pairs when dealing with live wires to provide assistance in the event of an emergency. Only individuals with specialized training should be permitted to handle high-voltage systems, and regular safety training updates are essential to maintain a secure environment.

### 2.6.1 Choice of Solution

Section 2.6.1 presents an overview of the systematic method for selecting the most effective configuration for a piezoelectric pendulum. The search for an ideal solution includes the analysis of critical components and techniques, including the selection of an appropriate microcontroller and piezo power source, as well as the determination of efficient piezo actuation and switching methods. This overview includes the examination of MOSFET control, the comparison between bootstrap circuits and isolated gate drivers, the decision to exclude an amplifier, the methods of impulse detection and considerations for casing design. Each of these subtopics is discussed in detail to provide a complete understanding of the decision-making process.

### 2.6.1.1 Microcontroller

The selected microcontroller must support a comprehensive programming language to accommodate the intricate functions required by the project. It is also essential for the microcontroller to possess fast hardware timers which are crucial for managing time-sensitive interruptions. Specifically, the detection of the returning ball by the piezo element should trigger a fast response from the microcontroller, pausing its current task to initiate a program designed for precise catching without bounce. Comprehensive documentation of the microcontroller is also important to facilitate the accurate programming of these critical time delays.

Additionally, the specification that the microcontroller should be compact was considered critical to maintain the convenience of the demonstrator. Moreover, the requirement for a minimum of 20 General Purpose Input/Output (GPIO) pins was deemed essential for my configuration. These pins are indispensable for enabling a variety of functions critical to the system's operation, such as controlling the piezo activation circuitry, voltage regulation, interfacing with a display, activating LEDs for power and signal detection, and linking an encoder and a push button.

The selection process for an appropriate embedded system platform entailed an analysis of crucial features, encapsulated in Table 1, which presents data on five prominent devices. Factors such as timer speed, memory capacity, and development environments were compared.

Because of their size, the Arduino Due and BeagleBone Black were excluded from consideration, as the demonstrator should not have overly large dimensions. Connecting a microcontroller with either a complex programmable logic device (CPLD) or a fieldprogrammable gate array (FPGA) offers a potential solution for managing time-sensitive functions, using their enhanced processing speeds. However, modifying their programs typically demands more specialized knowledge, which constitutes a barrier to their implementation in this project given the requirement for ease of use and adaptability. This complexity was a determining factor in deciding against their use.

Instead, the Raspberry Pi Pico emerged as the chosen microcontroller for this project, as delineated in Figure 23, because of its fast timer of 62.5MHz, small size and good documentation. This module has 26 multifunctional general-purpose input/output pins (GPIO) with pulse width modulation capability (PWM) and three analog inputs. The RP2040 microcontroller underpins the Pico, featuring a dual-core Arm processor with a 133 MHz clock speed, packaged efficiently in a cost-effective unit. Despite the presence of equivalent alternatives, the negligible price differential and projected longevity of the Pico validate its adoption.

Figure 23 Raspberry Pi Pico

Table 1 Comparing Embedded System Platforms

Feature | Arduino Due | BeagleBone Black | Raspberry Pi Pico | FPGA | CPGA
Category | Microcontroller | Microcontroller | Microcontroller | Field-program-mable Gate Ar-ray | Complex Pro-grammable Logic Device
Processor | Atmel SAM3X8E ARM Cortex-M3 | TI Sitara AM335x ARM Cortex-A8 | RP2040 Dual-core ARM Cor-tex-M0+ | Configurable Logic Blocks (CLBs) | Multiple FPGAs in a single pack-age
Timer Speed | 42 MHz | 200 MHz, using programmable real-time unit | 62.5 MHz | Varies | Varies
Memory (RAM) | 96 KB | 512 MB DDR3 SDRAM | 264 KB | Varies | Varies
Memory (Flash) | 512 KB | 4 GB eMMC Flash | 2 MB Flash | Varies | Varies
Size | 101.52mm*53.3 mm | 86mm*53.3mm | 51mm*21mm | Varies | Varies
Development Environment | Arduino IDE | Linux distribu-tion | MicroPython, C/C++, Arduino IDE | Hardware De-scription Lan-guage (HDL) | Hardware De-scription Lan-guage (HDL)
Learning Curve | Beginner-friendly | Intermediate | Beginner-friendly | Advanced | Advanced

### 2.6.1.2 Piezo Actuator

The P-820.30 linear piezo actuator from Physik Instrumente (PI) aligns with the project's specifications because of its high voltage range (up to 100V) and its capacity for substantial displacement within a compact size. Its 45-micrometer displacement capability is significant. This functional range is achieved in an actuator smaller than the one in Moldovan's 1993 device (which is no longer produced), making it suitable for the demonstrator. Moreover, its balance of aesthetic appeal and precise specifications, including force capacity and stiffness, ensures that it meets both the functional and design criteria of the project.

Further technical data of the actuator is on the next page:

Displacement at 0 to 100 V | 45 μm ±20 %
Static large-signal stiffness | 4 N/μm ±20 %
Push/pull force capacity | 50 / 10 N
Max. torque limit (on tip) | 0.08 Nm
Electrical capacitance | 1.0 μF ±20 %
Unloaded resonant frequency f0 | 12 kHz ±20 %
Mass | 14 g ±5 %
Length L | 62 mm ±0.3

The P-820.30 was acquired before this thesis began, and its application is based on its readiness, rather than a deliberate selection by the author. Its low capacitance is a downside, and it is recommended to buy a piezo actuator with a higher capacitance to avoid the resonance frequency. In the next section, I discuss the resonant frequency associated with the piezoelectric actuator.

Resonance frequency of piezo

This section delves into the dynamic interplay between the system's capacitive and resistive components and how this interplay affects operability and risk management. In particular, I will focus on achieving an optimal cutoff frequency to prevent the detrimental effects of resonance without compromising actuator efficiency. This discussion will culminate in a detailed analysis of the design choices made to balance performance and durability, thus providing a comprehensive understanding of the technical complexity of the actuator. In doing so, I aim to contribute to a more refined design method that prevents damage to the piezoelectric material while maintaining the required mechanical performance.

The piezo actuator in question possesses a capacitance of 1 microfarad (µF) and is subject to parasitic resistances originating from the actuator itself, connected wiring, and switching mechanisms. The used piezo has a resonance frequency of 12,000 Hz. It would be desirable to have a cutoff frequency f3db according to equation (5) beneath the resonance frequency to avoid the destruction of the piezo. It could oscillate so severely at its resonance frequency that the many layers of glued piezoceramic would separate (Moldovan, 1994a, p. 22) .

Equation (5) predicts a cutoff frequency of approximately 159 kHz when parasitic resistance is approximated at 1Ω. This simplification doesn't account for lower observed resistance values in the system components, potentially resulting in an actual cutoff frequency as high as 1 MHz.

It is difficult to measure the actual cutoff frequency without possibly damaging the piezo. The resonance frequency would have to be skipped as fast as possible in a test setupw. Lowering the cutoff frequency fp can be done by inserting an additional resistor (a current shunt) between the piezo and the switch, or by using a piezo actuator with higher capacitance. To achieve a target cutoff frequency of 10 kHz, inserting a resistor with a minimum value of 16 Ω is necessary, calculated using Ω, and Rp=

1
2 π f

pCp

from equation (5).

A 16 Ω resistor in series with the piezo significantly reduces current flow. This causes the actuator's force output to drop below practical levels, resulting in a shooting height for a 4g ball below 1 centimeter at 100V, as determined by experiments. Consequently, the shunt resistor was removed from the final design in order to maintain effective operation. While this omission increases the likelihood of actuator damage over time, the device's limited use justifies this method.

Compared to the piezo used by Moldovan in 1993, the contemporary PI P-820.30 actuator has 12% of the 1993 actuator's capacitance, adversely affecting the system's cutoff frequency. Moldovan's pendulum, equipped with a 2.7 Ω shunt resistor and an 8 μF piezo, attained a lower cutoff frequency of 7 kHz without substantially impairing amplitude (Moldovan, 1994a,
p. 22) .

Strategies to lower the cutoff frequency involve trade-offs, such as reduced actuator power, and hence, have been discarded in the current design to preserve functionality. Nevertheless, a 0 Ω resistor was added to simplify any potential future modifications. Comparison with previous work highlights the technical challenge in maintaining system performance while mitigating risks- a balance that remains integral to the design process.

### 2.6.1.3 Piezo Power Supply

The piezo can be used at voltages up to 100V DC. Table 2 shows four available options to reach such a high voltage. When selecting a suitable piezoelectric power supply, capable of operating at voltages as high as 100V, the key considerations included system simplicity, safety, necessity for low voltage input, adjustable output voltage, and maintenance of a minimal increase in weight.

The analysis concluded that the 12V DC with custom designed step-up converter circuitry was excessively intricate. Step-up converters inherently require additional components such as inductors, diodes, capacitors, and control mechanisms to facilitate voltage variation and stabilization. The inclusion of these additional components tends to complicate the overall circuit architecture, introducing additional points of failure that can adversely affect system reliability. In addition, achieving a consistent 100V output requires careful component selection and thorough circuit optimization.

The 230V to 100V AC transformer with rectifier was also assessed. It revealed significant safety concerns because its high input power could potentially increase the risk of dangerous incidents during testing. Additionally, this option might add considerable size and weight to the device, compromising its intended compactness, and the voltage would be fixed to 100V. Therefore, it was considered less ideal for the project requirements.

The PI 841.05 is a compact step-up power supply module developed by Physik Instrumente (PI) for use with piezo actuators. It was also eliminated because of its high cost, although it offered advantages in simplicity and safety.

As a result, the Recom R12-100B DC/DC converter was selected because it met the functional and fiscal requirements of the project, as well as ensuring safety at low input voltages and simplicity of design. A notable, viable alternative not mentioned earlier is the PDu100B by Piezodrive, which offers a 100V power supply and amplifier for $90.

Table 2 Comparison of voltage source options

Feature | 12V DC with custom designed Step-Up Con-verter circuitry | 230V to 100V AC Trans-former with Rectifier | 12V DC with PI 841.05 Step-Up Power Supply Module | Recom R12-100B DC/DC Converter
Input Voltage | 12V DC | 230V AC (mains power) | 10-30V DC (variable) | 12V DC
Output Voltage | 100V DC (adjustable) | 100V DC (fixed) | 127V DC (fixed) | 50 - 135V DC (adjustable)
Safety | Lower risk (low voltage input) | Requires caution with mains power | Lower risk (low voltage input) | Lower risk (low voltage input)
Cost | Moderate (converter only) | Low (transformer + recti-fier) | High (337€) | Moderate (45€)
Complexity | Moderate | Simple (transformer + rectifier) | Simple (single module) | Simple (single module)
Availabil-ity | Widely available | Widely available | Requires specific supplier | Widely available

### 2.6.1.4 Switching the Piezo

The piezo must be switched fast in the piezo pendulum, as the delay between ball detection and discharging must be precisely timed for a bounce-free catch, as discussed in the section 1.2.1.5. Metal-Oxide-Semiconductor Field-Effect Transistors (MOSFETs) exhibit the swiftest switching, superior to devices such as electromechanical relays and bipolar junction transistors (BJTs) which have slower operational speeds (Bogdanović et al., 2021, pp. 22–27) .

I measured the peak current flowing to the P-820.30 linear piezo actuator by shooting a ball using Moldovan's (1993) piezo control unit; it was around 50A at 90V. This measurement was performed with an oscilloscope using a resistor of known resistance, in conjunction with equation (6). Considering this finding, the switching mechanism's drain current should logically exceed the 50A threshold to accommodate the system's requirements.

Similarly, I measured the charging duration with Moldovan's piezo control unit, resulting in an approximate timeframe of 250 nanoseconds, as depicted in Figure 24. This period differs slightly in the final prototype as other electronics are used. Knowing this charging time is critical for establishing the duration the assumed switching mechanism must remain active to ensure the piezo is fully charged.

Figure 24 Voltage curve of P-820.30 actuator when charging

Although half-bridge modules with integrated MOSFETs and piezo drivers also demonstrate fast switching speeds, their performance is highly contingent upon individual integrated circuit design. For instance the Infineon IRSM808-204MH emerges as a small 20A, 250V half-bridge module (9mm x 8mm). It is characterized by its compatibility with 3.3V input logic and a notably low on-resistance of 0.15Ω. However, its construction within a PQFN (Power Quad Flat No-Lead) package presents complexities in the soldering process. This intricacy often necessitates advanced techniques and equipment. And because it can only be operated at a 20A output, I did not consider this idea further.

Piezo drivers, such as the DRV2700 device from TI on the other hand are especially developed to control piezo actuators, and often have the power supply included. But most of them were created especially for periodic oscillations and not intended for on-off switching operations. Lastly, they are often too slow for my purpose.

Therefore, given the paramount importance of rapid and reliable switching in driving piezoelectric devices, MOSFETs emerge as the superior option for the piezo pendulum.

### 2.6.1.5 Bridge Configurations

My study further investigates methods to energize the piezo actuator, narrowing down to half-bridge and full-bridge configurations. I have excluded an exhaustive review of piezo driving techniques, as prior studies, such as Gnad, 2005 , provide extensive analyses.

The full-bridge setup can charge a piezoelectric actuator to both a positive voltage, Vp in Figure 25 a), and a negative voltage, -Vp in Figure 25 b). This would double the voltage that the piezo receives, which according to (3), would quadruple the absorbable and releasable energy. Nonetheless, the piezo in my experiment is limited to a 0V to 100V range and cannot sustain a -100V charge without damage.

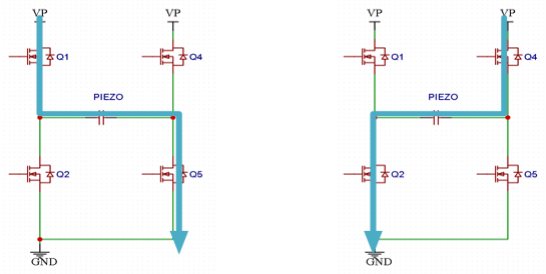
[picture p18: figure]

a) b)

Figure 25 Way of current when controlling the MOSFETs in a simple full-bridge setup; a) Piezo is charging; b) Piezo is discharging
Figure 26 shows a half-bridge setup. When the upper MOSFET Q1 is activated and Q2 is deactivated, the piezo charges Figure 26 a). When Q1 is deactivated and Q2 is activated, the piezo discharges Figure 26 b).

The half-bridge configuration's simpler design and cost-saving potential make it advantageous for my purposes. The design requires fewer components, which may reduce expenses and simplify the circuit design. However, it is critical to ensure that transistors Q1 and Q2 are not activated simultaneously to prevent shoot-through, a destructive phenomenon in MOSFETs (Figure 26 c).

The MOSFET on the high side (Q1) needs a higher gate voltage than the voltage at its source end, which connects to the positive terminal of the piezo device. I will discuss how to control the MOSFETs in the next two sections.

a) | b) | c

Figure 26 Way of current when controlling the MOSFETs in a half-bridge setup; a) Piezo is charging, only Q1 active;
b) Piezo is discharging, only Q2 active; c) Way of current at destructive shoot-through when Q1 and Q2 active

### 2.6.1.6 Control Strategies for MOSFETs

Now that the half-bridge configuration has been chosen, an effective control strategy must be used to control both MOSFETs, with options including microcontroller direct drive, forward converters, and gate driver ICs.

Microcontroller direct drive offers a simpler alternative where a microcontroller provides signals directly to the MOSFET gates. It is inexpensive and straightforward, ideal for low-power situations. However, it is limited in drive capability, more susceptible to noise, and may require additional components for stability, especially in high-side switching. Because the microcontroller can only provide 3.3 volts—insufficient to fully turn on a MOSFET suitable for 100V operation—this method is not feasible in my case.

Forward converters are adept at generating the necessary gate voltage for MOSFETs, particularly useful when stepping up from a lower DC input to a higher DC gate drive voltage. Moldovan (1994) used two forward converters, see the transformers connecting to the gate of the MOSFETs in Figure 11. These devices use a transformer to provide a constant output and provide galvanic isolation, so that voltage-spikes from the high-side cannot affect the digital circuit. However, adding forward converters increases the complexity of the circuit, making the circuit larger and the device heavier.

Gate driver circuits use special ICs that provide strong isolation from high power areas and protection against electrical noise. This method is suitable for complex applications like the piezo pendulum, where high-side switching is required, and the design is generally more straightforward, requiring fewer parts.

Consequently, a discrete gate driver was chosen for its simpler design. However, this choice raises the issue of driving the high-side MOSFET (Q1 in Figure 26). Because its source terminal connects directly to the positive node of the piezoelectric actuator, it requires a gate voltage exceeding this node's voltage. This could be achieved by using various methods. Therefore, a critical comparison is required.

### 2.6.1.7 Driving the High-Side MOSFET:

Bootstrap circuits, isolated gate drivers, or forward converters can be used to switch the high-side MOSFET in the half-bridge configuration. Table 3 shows a detailed comparison between the devices.

Firstly, an isolated gate driver requires a transformer or isolated DC-DC converter, and provides uninterrupted operation, meaning it can turn on a MOSFET continuously. As the name indicates, the device provides galvanic isolation. However, it comes at a higher cost and adds complexity to the circuit.

Forward converters were discussed in 2.6.1.6, but now I am discussing only driving the high-side MOSFET. As mentioned, forward converters provide galvanic isolation but may require a custom-made transformer, resulting in a more extensive and expensive assembly.

Moving on, Figure 27 illustrates a basic bootstrap configuration: Initially, with no charge, the potential of MOSFET Q1 mirrors that of ground. During this phase, capacitor C accumulates charge up to the supply voltage Vcc through the diode. As the piezo accumulates charge, Q1's source rises above ground, affecting system dynamics. The fully charged capacitor C, impeded by the diode, maintains the full voltage across Q1's gate source when the switch is engaged, driving the MOSFET to full saturation (Günther et al., 2013, p. 32) .

A bootstrap circuit, using a gate driver IC instead of the mechanical switch in Figure 27, does not provide galvanic isolation. Instead, it offers simplicity through fewer needed components. Their straightforward design and commercial availability make them accessible and relevant for the intended use. I selected the bootstrap method for its simplicity and cost-effectiveness. It stands out for easy implementation and broad availability but presents challenges, including a limited duty cycle—the MOSFET cannot be continuously active because it relies on the boot capacitor's charge—and the absence of galvanic isolation. Consequently, careful choice of boot capacitor and boot diode is a primary focus in the design process.

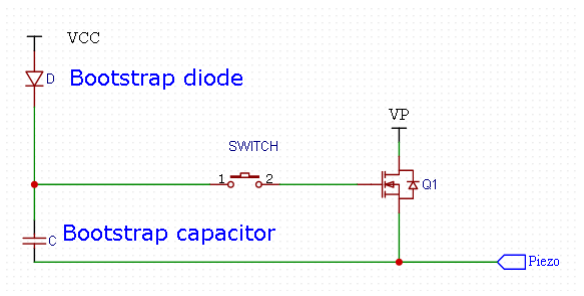
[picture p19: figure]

Figure 27 Simple bootstrap circuit

Table 3 Comparison between bootstrap circuit, isolated gate driver and two forward converters

Feature | Forward converters | Bootstrap configura-tion with gate driver | Isolated gate driver
Galvanic isolation | Yes | No | Yes
Uninterrupted opera-tion | Yes | No | Yes
Number of components | More | Less | More
Transformer | Required, eventually custom build | Not required | Required or isolated DC-DC converter
Size | Bigger | Simpler | Bigger
Cost | More expensive | Less expensive | More expensive
Ease of implementation | More complex | Simpler | More complex

### 2.6.1.8 Absence of Piezo Amplifier in Control Circuitry

An amplifier serves as an essential device for boosting the signal strength of a control circuit, allowing precise manipulation of outputs such as the voltage of a piezo actuator (Vp). Without an amplifier, it is difficult to make quick and accurate adjustments to the voltage. The ability of an amplifier to make rapid changes is critical when adjusting the launch height of a ball at rapid intervals. It also allows the pendulum to create a variety of acoustic effects, such as mimicking musical beats by creating louder sounds with longer pauses using high voltage, or softer sounds with shorter pauses using low voltage, which would certainly be an exceptional feature for a demonstrator.

However, despite its advantages, the circuit design ultimately did not include an amplifier. The PI E-831.05 amplifier from Physik Instrumente (PI) was considered because of its compatibility with the PI P-820.30 piezo actuator, its compactness, low noise, and stability. It was not used because of its high cost (205 Euro) and long delivery time (8-10 weeks). Because the amplifier is not critical to the demonstrator's basic functions, I determined that these barriers outweighed its potential benefits.

### 2.6.1.9 Impulse Detection

When the pendulum's ball strikes the piezoelectric actuator, the microcontroller must detect it in my setup. To do this there are various methods, listed in Table 4:

While a Schmitt trigger could eliminate erroneous signals, and a digital signal processor (DSP) offers extensive flexibility, the DSP's complexity is unnecessary for my requirements.

A viable method involves using a high-speed analog-to-digital converter interfaced with a
microcontroller | for | software-based | impulse | processing. | For | example | the
ADC08100CIMTC/NOPB captures voltage at a rate of up to 100 million samples per second; this setup allows for easily adjustable thresholds via software.

Although operational amplifiers with feedback are applicable for impulse detection, comparators are preferable because of their rapid response.

Consequently, I chose a window comparator for its simplicity, adequacy for the intended function, and proven efficacy, as demonstrated by Moldovan, 1994a, p. 12 .

Table 4 Comparison of possible methods for impulse detection

Method | Description | Advantages | Disadvantages
Window Comparator (used by Moldovan, 1994a, p. 12 ) | Uses two comparators to define a window for the expected impulse signal. | Simple and reliable for basic detection, thresholds can be changed with poten-tiometers | Sensitive to variations in signal strength.
Schmidt Trigger | Cleans signal and triggers on clear rise/fall above threshold. | Improves noise immunity, prevents false triggers. | Adds complexity compared to window comparator.
Microcontroller with ADC | Monitors voltage and trig-gers on programmed threshold. | Very fast options available, allows for advanced pro-cessing. | More complex setup, ex-pensive
Digital Signal Processor (DSP) | Analyses signal in real-time using algorithms. | Most versatile, allows for complex filtering and re-cognition. | Expensive, requires signific-ant expertise.
Op-amp with Feed-back | Configurable comparator with adjustable sensitivity. | Offers adjustable threshold and clear output signal. | Normally slower than win-dow comparators

For a detailed understanding of each theoretical concept, refer to the work of Tietze et al., 2016 .

### 2.6.1.10 Casing

The proposed case designed for 3D printing facilitates rapid prototyping. The inherent ease of modification in this process allows for precise personalization to unique requirements, providing an efficient method for creating custom cases. In addition, the aesthetics of the design can be enhanced to improve its visual appeal. By mounting the piezo actuator directly onto the control unit rather than on a separate base, as shown in Figure 9, the susceptibility of the wires to damage is significantly reduced.

### 2.6.1.11 Absence of Portable Power in Control Circuitry

While Moldovan’s device used batteries, this one will be designed without batteries. The device remains simple, compact, and lightweight. It is intended for stationary use in educational settings, which mitigates the need for portability.

### 2.6.1.12 Summary of Design Decisions So Far

Table 5 consolidates the decisions made for the piezoelectric pendulum system's configuration so far, reflecting a careful balance between performance, simplicity, cost, and practical application.

Table 5 Summary of design decisions made in chapter "Choice of Solution"

Component Name | Description | Rationale
Microcontroller (2.6.1.1) | Raspberry Pi Pico | - Supports comprehensive programming lan-guages - Fast 62.5MHz hardware timers - Ample documentation
Piezo Actuator (2.6.1.2) | Physik Instrumente P-820.30 | - Meets demonstrator requirements - Appealing design
Piezo Power Supply (2.6.1.3) | Recom R12-100B DC/DC Converter | - Meets safety, simplicity, cost, and input voltage requirements
Piezo Switching (2.6.1.4) | MOSFETs | - Superior switching speed - Reliable for fast piezo actuation
Bridge Configuration (2.6.1.5) | Half-Bridge Setup | - Simpler, cost-effective, and efficient design
MOSFET Control (2.6.1.6) | Gate Driver Circuit | - Simpler design
Driving the high-side MOS-FET (2.6.1.7) | Bootstrap Circuit | - Cost-effective - Simpler design
Piezo Amplifier (2.6.1.8) | Not Included | - High cost and long lead time - Not essential for basic demonstrator operation
Impulse Detection (2.6.1.9) | Window Comparator | - Straightforward implementation - Proven performance in similar applications
Casing (2.6.1.10) | 3D Printed | - Facilitates rapid prototyping - Allows custom design adaptations - Enhances design aesthetics
Portable Power (2.6.1.11) | Not Included | - Simpler design - Intended for stationary educational use

### 2.6.2 Functional Model

Building on the basic framework outlined in the previous section, this section concentrates on choosing appropriate electronic components. The creation and procurement of the Printed Circuit Board (PCB) are then described. These steps are essential to enhance the preliminary structure into a fully functional model.

Firstly, Figure 28 shows an overview of the hardware components used in the functional model. The piezo actuator is controlled by a series of signal exchanges, starting with the microcontroller, which uses input/output ports and is connected to an impulse detection system. It sends instructions to a gate driver, which then controls MOSFET switches to charge the piezo. The microcontroller also provides updates to the LEDs and interacts with a display and encoder. Power is supplied externally via a 12V input, which is appropriately adjusted: the digital circuit receives its voltage of 3.3V via a step-down converter and the piezo actuator receives its adjustable voltage of 50 to 100V via a step-up converter.

•

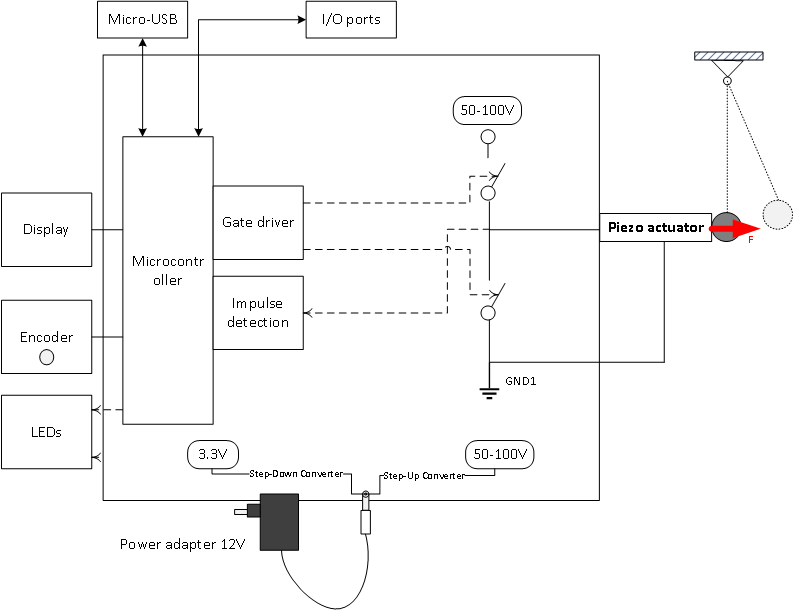
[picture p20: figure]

- Figure 28 Simplified hardware overview of functional model
Secondly, Figure 29 presents the completed Printed Circuit Board (PCB), detailing the arrangement and connections of constituent components. A 5.5mm power jack facilitates the application of 12V DC from an external power adapter. The design includes a socketed microcontroller that allows for the interchangeability of other 2x20 pin microcontrollers. Connectivity for the display, LEDs, and the encoder is achieved through a 2x8 pin connector. Finally, to connect the piezo, a 1x2 pin socket with a guiding feature ensures correct orientation, preventing incorrect polarization and potential damage to the piezo element.

•

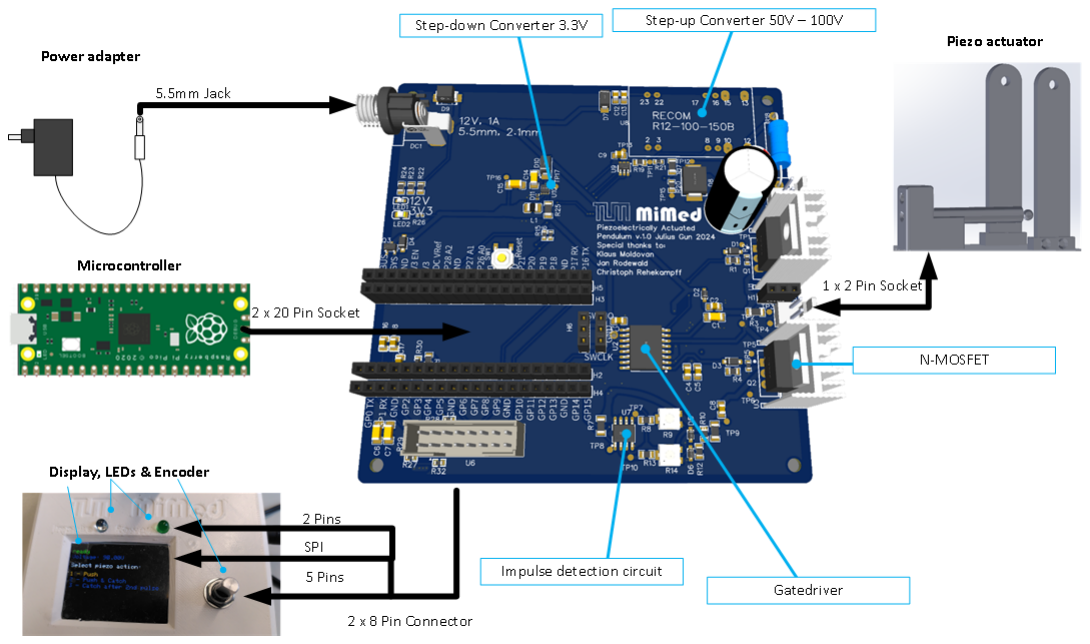
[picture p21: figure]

- Figure 29 Equipment setup: How the parts are connected to one another

In the following subsections, I explore the model's building blocks. I start with power MOSFETs, key elements for switching the piezo, then move to the bootstrap half-bridge gate driver, integral for managing the MOSFETs. The power supply is discussed as the foundational support providing energy, followed by user interaction, which describes how individuals interface with the device. The ball used for the experiment is examined next. Subsequent sections dissect PCB design, including circuit layout. I also look at the software that drives the system's functionality and end with impulse detection, detailing how the system senses the returning ball.

### 2.6.2.1 PCB Design

The completed Printed Circuit Board (PCB) design is displayed in Appendix B and all schematics in Appendix A. In designing the PCB, I pursued the following strategies:

Firstly, I chose simple components to reduce assembly complexity and cost, as assembly by JLCPCB in China incurs additional expenses for "extended" parts, such as non-SMD or rare components. I used inexpensive parts, as documented in Appendix C. For instance, I used series-connected resistors in some cases instead of a single "extended" part (see Figure 35 for example) and occasionally employed parallel capacitors to achieve the required capacitance.

Additionally, the design conformed to guidelines suggested by Scherz, 2007 , segregating the high voltage and digital sectors on the PCB, which measures 100x100mm. Efficient routing was prioritized, placing the microcontroller and high-frequency circuits like I2C and SPI near the power source. Decoupling capacitors were systematically placed to minimize logic spikes and electrical noise.

That being said, the design lacks galvanic isolation between the digital and high-voltage circuits (they share one ground), posing a risk of electrical interference and potential damage to components. Galvanic isolation would have made the circuit much more complex and was thus not implemented. While using optocouplers could provide isolation and improve safety, it would necessitate a redesign of the piezo power supply and other components. Nonetheless, two grounding systems, GNDD (for digital parts) and GND (for common parts), were designed and linked later to pave the way for possible future implementation of galvanic isolation.

Lastly, the PCB features numerous TestPoints (TP) for oscilloscopic analysis of signals and voltages. These TestPoints facilitate direct probing of electrical pathways, essential for assessing PCB performance. They prove invaluable for pinpointing faults and validating the design during the circuit development phase.

### 2.6.2.2 Power MOSFETs

MOSFETs are used to rapidly change the piezoelectric device's state, as discussed in the section
2.6.1.4. The chosen Infineon IRFB4115 provides a drain current significantly higher than the 50A required by the actuator, as described in the section 2.6.1.4.

MOSFET technology has advanced substantially compared to the technology available three decades ago. This indicates significant development since Moldovan's prototype was created, as Table 6 shows. The table compares the BUZ350 used by Moldov and the new IRFB4115. For further understanding of the technical terms being used, one can refer to Tietze et al., 2016 .

The IRFB4115 MOSFET can conduct current up to 104A continuously. And because it is activated only for a short time, only the IDM Pulsed Drain Current is relevant. This current is 420A, providing a significant margin over the target drain current. Its selection was based on a favorable balance of performance and cost, considering that lower-performance options cost about the same. The VDS Drain-to-Source Voltage also leaves some margin for voltage spikes, because voltages higher than 150V could damage the MOSFET.

This MOSFET model has an activation time of only 18 nanoseconds and a very low drain-tosource on-resistance (RDS). These characteristics are favorable for achieving rapid charging, because a swift voltage rise enhances the energy absorption rate and subsequent conversion to kinetic and potential energy, as detailed in the section 1.2.1.3. Despite the benefit of rapid charging, a longer activation time is not detrimental. It may reduce the cutoff frequency (equation (5)), an effect that can be mitigated by the introduction of a shunt resistor, as elaborated in subsection 2.6.1.2.

The MOSFET's brief activation, limited to tens of microseconds, contrasts with the ball's longer airborne phase of hundreds of milliseconds, allowing natural convection to suffice for heat dissipation. However, to provide additional thermal protection, heat sinks are attached to the MOS-FETs. This precautionary measure aims to prevent overheating during operation, thus ensuring the reliability and longevity of the device.

Table 6 Comparison between MOSFETs: BUZ350 used by Moldovan (1994) and new IRFB4115

MOSFET | BUZ350 used by Moldovan (1994) | IRFB4115
RDS 2 (on) (@10V) max | 120 mΩ | 11 mΩ (Over ten times lower)
VDS 3 max | 200 V | 150 V (Lower voltage rating of piezo actuator)
ID 4 Continuous Drain Current | 22 A | 104 A (Over five times higher capacity)
5 IDM Pulsed Drain Current | 85 A | 420 A (Over five times higher capacity for pulsed operation)

2 RDS= Drain-to-Source On-Resistance

3
VDS= Drain-to-Source Voltage

4
ID= Continuous Drain Current is the maximum current a MOSFET can handle continuously without damage.

IDM= Pulsed Drain Current is the maximum current a MOSFET can handle in short bursts.

### 2.6.2.3 Bootstrap Half-bridge Gate Driver

The section 2.6.1.7 presents an analysis of bootstrap circuits relative to other options, culminating in my selection of a bootstrap circuit as most suitable for this development. Using a bootstrap circuit contributes to a more efficient circuit design, decreasing size and intricacy, which simplifies production. Additionally, the final device is lighter because it lacks transformers, which are crucial in forward converters.

The final bootstrap circuit is illustrated in Figure 30. This circuit incorporates a bootstrap capacitor configuration-comprising two capacitors in parallel. Using a bootstrap capacitor charged during the high-side MOSFET's off-cycle allows the circuit to maintain a gate voltage above the source voltage. This ensures the high-side MOSFET is driven into full conduction. The bootstrap diode D2 is used to generate a voltage exceeding that of the main power supply, Vcc. This elevated voltage is instrumental in the activation of the high-side MOSFET Q1. The diodes D1 and D3 ensure that the MOSFETs are protected from potential voltage spikes that could occur. Resistor R3 has 0 Ohms and could be replaced later, as discussed in the subsection
2.6.1.2. The heatsinks U1 and U3 provide thermal cooling to the MOSFETs.

I use the IR2110STRPBF from Infineon, a half-bridge gate driver, to control two MOSFETs, Q1 and Q2. A gate driver is an essential component in power electronics that serves as an intermediary between control signals (often from a low-power microcontroller or signal processor) and power MOSFETs. It is necessary because it amplifies the control signals to the appropriate levels required to switch the MOSFETs on and off effectively and efficiently. Without a gate driver, the MOSFETs may not receive a high enough voltage to transition rapidly between states, which can lead to increased heat dissipation and slower operation. The IR2110STRPBF offers fast actuation with a 120ns turn-on time, includes safety features like an under-voltage lockout, and is supported by abundant online resources for ease of use.

The microcontroller is configured to transmit two signals to the driver, as depicted in Figure 26: one signal for controlling the high-side MOSFET (HIN) and another for the low-side MOSFET (LIN). In my specific application, the HIN signal to Q1 activates the piezoelectric element. Upon activation, the piezoelectric element propels the ball, which subsequently rebounds, triggering an impulse detection mechanism that initiates a counter. The piezoelectric element's high state is disengaged via the LIN signal to Q2.

It is crucial to note that the selected gate driver lacks inherent shoot-through protection. This condition can occur if both high-side and low-side MOSFETs turn on simultaneously, potentially causing catastrophic MOSFET failure, as discussed in the section 2.6.1.5. To mitigate this risk, I took meticulous precautions in the programming code to prevent concurrent activation of both signals, thus preserving MOSFET integrity and functionality. There are other gate drivers with shoot-through protection, such as the Infineon 2ED2182-4-S06F, but acquiring them can be challenging, while the IR2110STRPBF is readily available.

Figure 30 Gatedriver circuit

### 2.6.2.1 Impulse Detection

When the ball hits the piezoelectric actuator, the microcontroller detects a voltage shift via the comparator circuit. I employ the window comparator setup, described by Moldovan, 1994a,
p. 12 , is employed for impulse recognition at the moment of impact, as discussed in section
2.6.1.9. A window comparator checks if an input voltage resides within a specific voltage range, set by two predefined reference levels (Tietze et al., 2016, p. 601) . The reference levels in my configuration are +40mV and -100mV. Moldovan determined these experimentally, and I have also validated them for the P-820.30 actuator. When choosing another piezo actuator, other reference levels might have to be determined.

Figure 31 illustrates the circuit; the "IMPULSE" from the piezo enters from the right. Here, capacitor C8 filters out the DC offset, allowing only current fluctuations to pass. Resistor R11 reduces current flow. Clamping diodes D5 and D6 ensure the comparator's input voltage remains between -1V and +4V, as it would otherwise reach up to 100V. To adjust the voltages at testpoints TP7 and TP10, one must connect a multimeter appropriately. The red probe of the multimeter is to be attached to either TP7 or TP10, while the black probe is to be connected to TP9. This setup allows for the accurate measurement and calibration of the voltages at the designated testpoints through the manipulation of potentiometers R9 and R13.

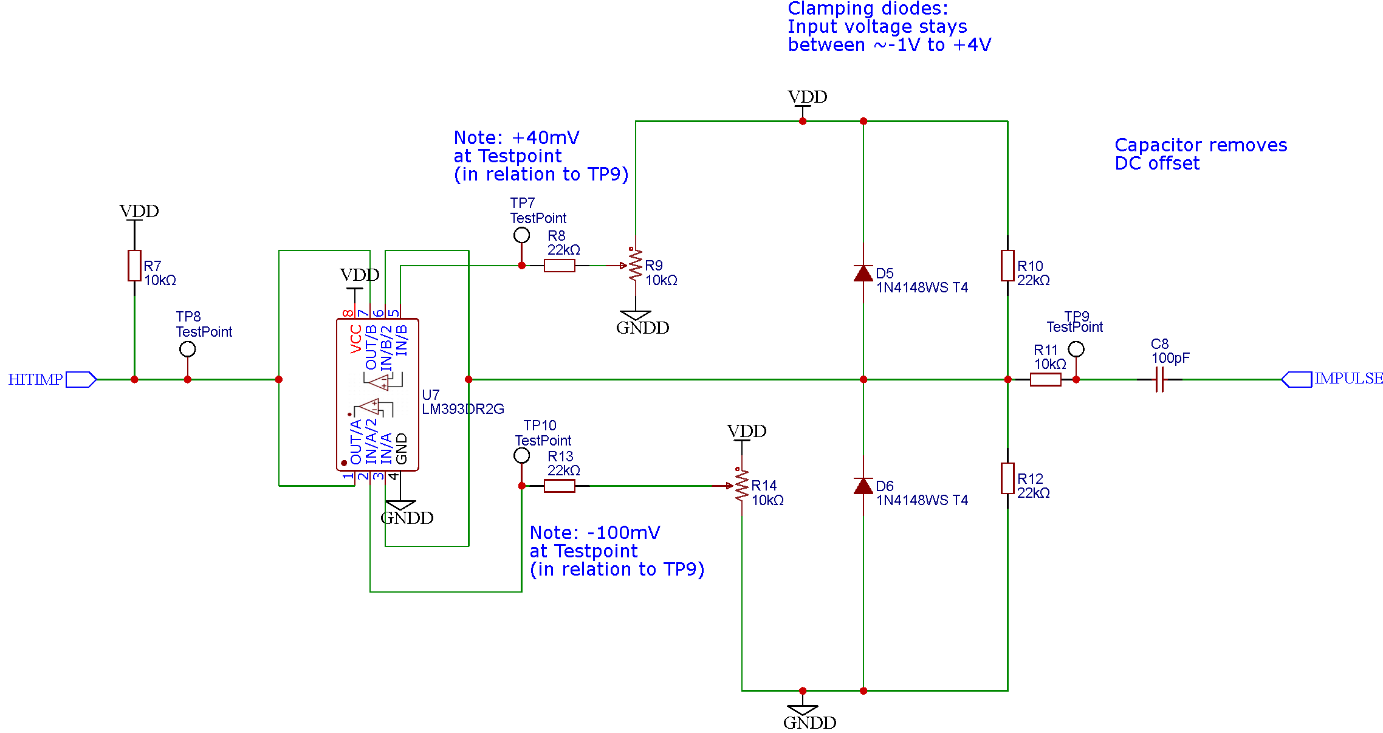
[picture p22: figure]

Figure 31 Impulse detection circuitry (based on (Moldovan, 1994a, p. 12) )

### 2.6.2.2 Power Supply

The unit is powered by an adapter that supplies 12 volts of DC (VCC) at 1A. The voltage VCC is then reduced to 3.3 volts to accommodate the digital circuitry. Concurrently, VCC is boosted to 100 volts to power the piezoelectric component.

### 2.6.2.2.1 Piezo Power Supply

The Recom R12-100B DC/DC converter, designated as U8, energizes the piezo illustrated in Figure 32. Charge-retention is enabled by buffer capacitors C10 and C11, which provide energy upon activation of the piezo. Additionally, the Recom R12-100B requires a baseline load of 10mA for proper operation, a demand met by resistor R10. Diode D8 offers overvoltage protection by capping the potential at 100V, thus safeguarding the piezo.

Further on, the microcontroller reads the current voltage at the piezo Vp via the signal Analog_V_measure through a voltage divider of R17 and R20. To provide a margin to accommodate occasional voltage surges the upper limit for voltage detection by the microcontroller is fixed at 2.2V for a piezo voltage (Vp) of 100V, according to the basic formula:
(
R20

R17+R20 )
×100V =2.2V

Within its operational capabilities, the Recom R12-100B can output a voltage between 50 and 100 volts, even though reaching up to 135 volts is technically possible. To adjust the voltage on component U8, one can apply a control voltage ranging from 0 to 4 volts between the VADJ and GND terminals. This adjustment can be achieved using either a digital-to-analog converter (DAC) or a digital potentiometer; for this study, I chose the 8-bit DAC5571 by Texas Instruments as a suitable component.

The microcontroller communicates with U8 via an I2C signal to regulate its voltage. This signal is directed to U9, the digital-to-analog converter, with output voltages depicted in Figure 33. At a VADJ output of 0V, VP measures 50V; when VADJ reaches 3.3V, the maximum for my digital circuits, VP climbs to a piezo-threatening 120V. To safeguard against overvoltage, a voltage divider, comprising resistors R19 and R21, follows the digital-to-analog converter, capping the output at 2.35V-thereby preventing activation of the piezo beyond 100V.

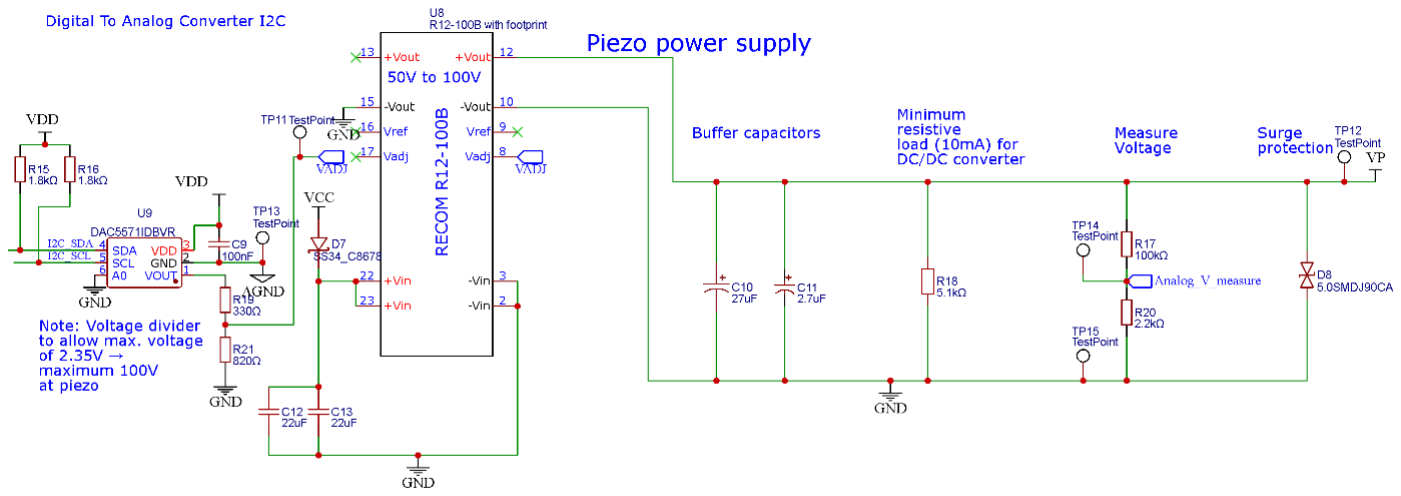
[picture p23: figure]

Figure 32 Piezo power supply

Figure 33 Voltage at the piezo Vp over the the input voltage VADJ, the voltage that is provided after the voltage divider at Testpoint 11 in Figure 32
But the voltage at the piezo is less than 100V, because activation triggers a voltage decline in the piezo due to charge redistribution from buffer capacitors, as depicted in Figure 34.

Initially, the buffer capacitors charge up to a Vp of 100V (left); subsequently, the engaged piezo causes them to discharge. The voltage source's minor current influence is omitted in this context. Mathematical delineation indicates the piezo actuator acquires a voltage near 96.8V, given the piezo's capacitance of 1µF and the buffer capacitors' total capacitance of 30µF. Hence, the deduced voltage at which the piezo operates is 96.8V, after capacitor discharge, keeping a small buffer between its maximum operational voltage of 100V. The associated Matlab code in Appendix G applies these values to compute the resulting charge and voltage during the discharge process.

The charge is calculated using equation (1) by distributing the initial charge (Q1_1) between the piezo and the buffer capacitors, proportional to their capacitances. This redistribution is crucial because the piezo and the buffer capacitors form a network where charges are shared according to their respective capacitances. Hence, the formula for Q2_2 uses the ratio of the piezo's capacitance to the total capacitance of the system, multiplied by the initial charge Q1_1, to find out how much charge ends up on the piezo after discharge.

a) b)

Figure 34 Role of buffer capacitors in charging the piezo; a) Piezo is not charging; b) Piezo is charging

### 2.6.2.2.2 Power Input

A 12V DC input is furnished through the power jack DC1, as shown in Figure 35. Following this, I chose series resistors (as mentioned in the section 2.6.2.1) to lower the current the indicator LED received, and surge protector D9 is in place. This component shields against potential damage from voltage spikes. It is essential for maintaining the integrity of the circuit's operation. Downstream, two DC/DC converters are tasked with energizing the digital components and the piezo.

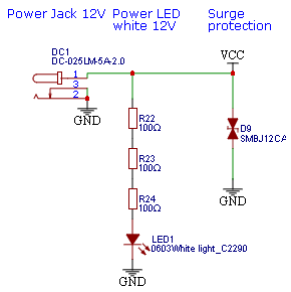
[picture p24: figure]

Figure 35 Power jack

### 2.6.2.2.3 Step-down converter

The step-down converter U10 supplies a stable 3.3V to all digital components on the circuit, with the operational status indicated by a green LED on the PCB:

Surge protector D11 safeguards digital circuits against excessive voltage. The other capacitors and inductor are necessary for the device to work properly, and values were chosen according to the U10 datasheet.

Figure 36 DC/DC converter - 12V to 3.3V
Power to the microcontroller is channelled through its VSYS port, which is engineered to handle an input voltage range from 1.8V to 5.5V, a fact highlighted in Figure 37.

The P-MOSFET Q3 operates as a switch, severing the VDD source circuit when the microcontroller is powered via USB. This ensures power is sourced exclusively from the USB when available, preventing potential overvoltage from dual power sources. Should USB power cease, the P-MOSFET restores the connection, allowing VDD to supply the necessary voltage to the microcontroller. This design elegantly ensures the microcontroller is powered without interruption while safeguarding it from electrical damage.

Figure 37 Power connection to Raspberry Pi Pico

### 2.6.2.3 User Interaction

I considered that the display needed to be at least two inches for readability, preferring a color screen for aesthetic appeal in menu design. I deemed including touchscreen functionality unnecessary, as it would make the system more complicated to use. The user interface in this project uses a 2-inch display with an ST778R chip (model DFR0664 from DFRobot) and an encoder with push functionality for interaction. Figure 38 shows the display connecting ports; it uses the SPI (Serial Peripheral Interface) protocol for communication with the microcontroller. An SD card can be used to store or retrieve data, for instance, a logo.

Figure 38 Display connections
The next image displays a rotary encoder with an integrated pushbutton. This enhances the overall appearance by eliminating the need for an additional button. The consolidation into a single unit not only saves space but also simplifies user interaction. I employed multiple pull-up resistors and decoupling capacitors to mitigate noise interference.

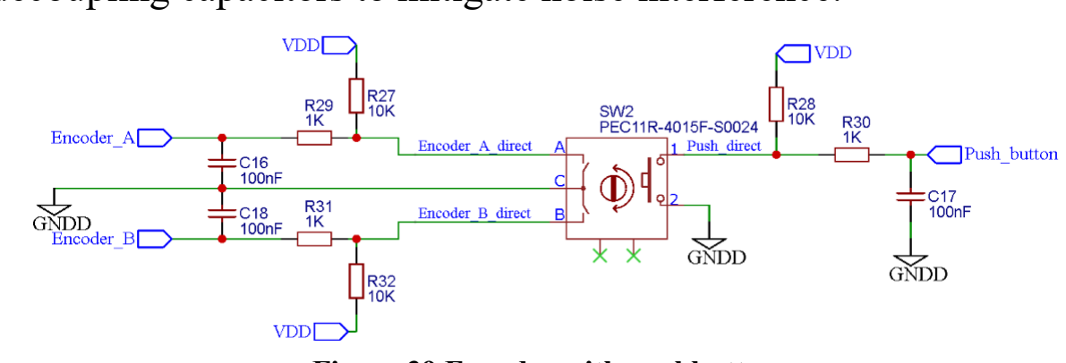
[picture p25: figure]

Figure 39 Encoder with pushbutton
The subsequent illustration shows that a connector is used to link the electronics of the front piece, which comprises a display, two LEDs, and an encoder. A green LED, designated as LED3, signals the power status, while a blue LED, named LED_IMPULSE, illuminates for a predetermined duration upon the detection of the ball.

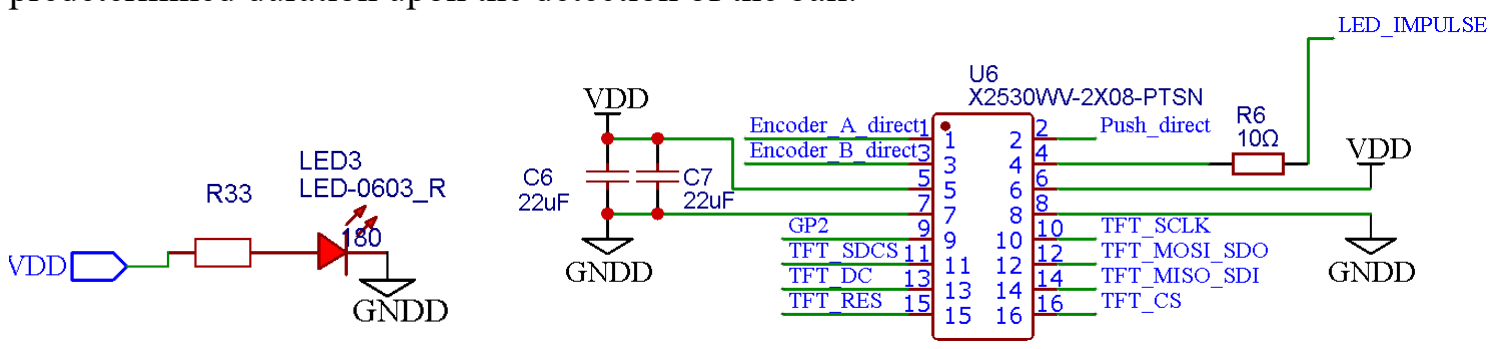
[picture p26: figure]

Figure 40 Connector for Display, LEDs on front & Encoder

### 2.6.2.4 Ball

The steel ball comes from a ball bearing and has a copper wire soldered to it. The ball must first be sanded before soldering for enhanced friction, the result can be seen in Figure 41. The ball weighs 1.4g. Experimental trials using a 4-gram ball yielded shooting heights that lacked sufficient interest for demonstration purposes, leading to the selection of a lighter ball. It is possible to use a ball made of any material, provided it can be appropriately mounted.

Figure 41 Ball with soldered copper wire.

### 2.6.2.5 CAD design

I conducted the Computer-Aided Design (CAD) process using Solidworks software. Illustrations of the resulting designs are available for review in Appendix F. Throughout the final prototype's development, I 3D-printed six distinct cases to determine the most appropriate design, as shown in Figure 42. This iterative method allowed for thorough exploration and refinement of design options.

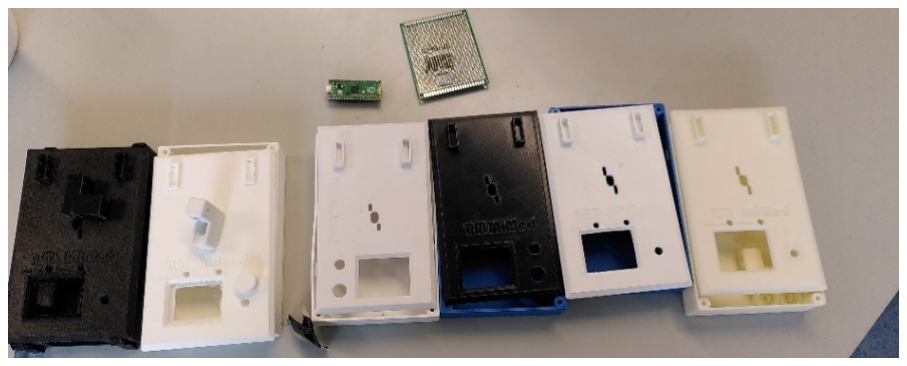
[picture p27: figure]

Figure 42 Iterations of the 3D printed cases.
In the construction of the described device, M3 and M2 threaded inserts serve as anchoring points for screw attachments, facilitating secure and stable connections within the plastic components. The control cover attaches to the housing using four M3x10 screws, ensuring a firm enclosure. Additionally, I secured the PCB (Printed Circuit Board) in position using four M2x5 screws, which contribute to the unit's structural integrity.

Thread supports, fashioned from acrylic glass through laser cutting, ensure high precision and a smooth finish. These elements are anchored securely using conical M2x5 screws, which provide stability and ease of maintenance for the assembly:

a) b)

Figure 43 a) Thread supports; b) Thread holding screw
Further adjustable aspects, such as the string height, are facilitated by an M6x50 screw, which features a hole at its end to accommodate adjustments. This adjustment screw can be locked in place with an M3x12 screw, which is secured by an M3 insert, as illustrated in b) above.

### 2.6.2.6 Flowchart of Software

This section elucidates the chronological procedure implemented in the software's code, examined with the aid of Figure 44. A comprehensive flowchart of the software is available for reference in Appendix D. The software code itself can be seen in Appendix E.

Figure 44 shows the sequence of operations for navigating through the menu. The initialization sequence includes setting an interrupt for pulses, adjusting the voltage, and configuring variables. Delays in the 'timerDelays' array are critical for timing the capture process, with the first item starting with an 8 microsecond delay after one bounce, 5 microsecond delay after two bounces and so on. These delays can be changed by pressing and holding the pushbutton for two seconds. Users interact with the menu using an encoder and a button, while a software debounce mechanism mitigates accidental selections. The program has three main functions: "Push," "Push and Catch," and "Resonance."

To select a function, the user must press the pushbutton for longer than the predefined debounce time to mitigate noise and random activation. After completing a selected activity, the user can choose another operation; however, this subsequent selection process is not depicted because of spatial constraints.

The "Push" program discharges the piezo while the ball is airborne. In contrast, the "Push and Catch" mechanism discharges the piezo upon ball detection after a predetermined interval set by `timerDelays`. Meanwhile, the "Resonance" mode responds immediately to an impulse interrupt by discharging the piezo without delay. In particular, the "Push and Catch" and "Resonance" functions can initiate the catching process after a predetermined number of bounces (one, two, or three); this detail is condensed to accommodate limited space in the chart.

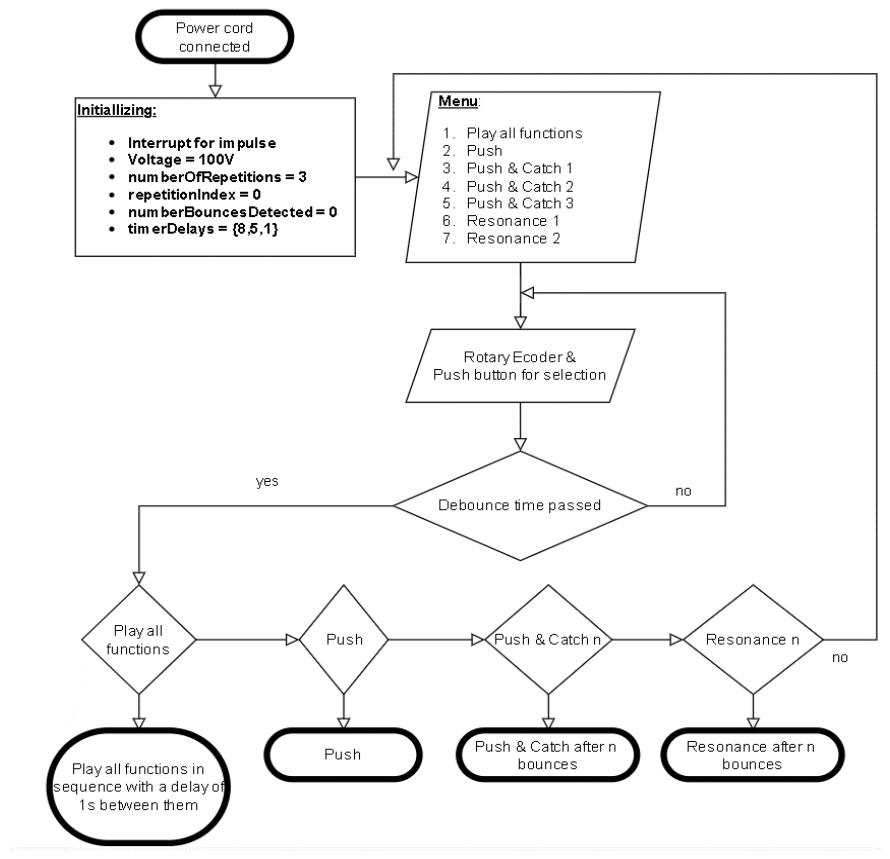
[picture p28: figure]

Figure 44 Flow chart of menu selection process

Figure 45 shows only the "Push and Catch" program because of its significance for the demonstrator and because all other programs are slight variations of it. It has further been simplified to accommodate limited space in the chart. A comprehensive flowchart that includes the other functions is available for reference in Appendix D. When the program "Push and Catch" is selected, the lower side MOSFET Q2 is turned on for 30 microseconds to charge the bootstrap capacitor. Then it is turned off, and after a delay of one microsecond to prevent shoot-through, it turns on the higher side MOSFET Q1 for 100 microseconds.

The piezo charges within approximately 250 nanoseconds but only after a delay. This is because the response of the piezo is not instantaneous once high voltage reaches the ceramics. I discuss the details of this actuator response delay and its effect on MOSFET turn-on time in more detail in a later section (see Figure 52 b) for initial insight). Because the ball remains airborne for a duration substantially exceeding the charging time, I deemed an activation span of 100 microseconds for Q1 sufficient, even though it surpasses the minimal necessary interval. Once Q1 is disengaged, the system enters a quiescent state, implemented by a while-loop.

The processor subsequently resides in an idle state until it perceives an impulse interrupt, signifying the detection of the ball. When this interrupt is received, the processor's forthcoming action is postponed for an interval as decreed by timerDelays[n = 1], with 'n' equating to the number of detected ball bounces. For one bounce, this delay is eight microseconds, as indicated in the `timerDelays` array initialization (related to Figure 44). Following the postponement, the lower-side MOSFET, Q2, is once again activated, which results in the discharging of the piezo and facilitates a bounce-free catching of the ball. After this sequence, the system is primed for a

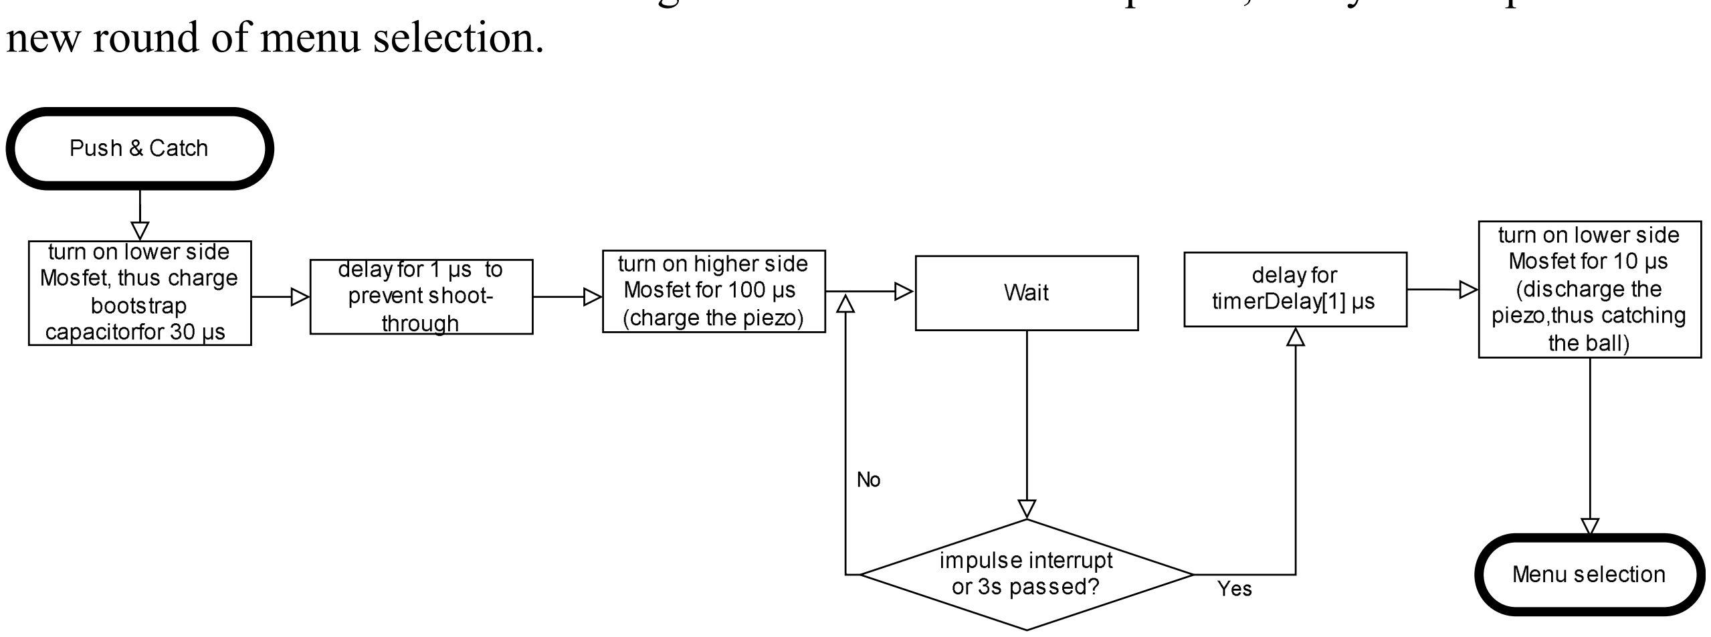
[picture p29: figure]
new round of menu selection.

Figure 45 Flow chart of “Push and catch after one bounce”
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

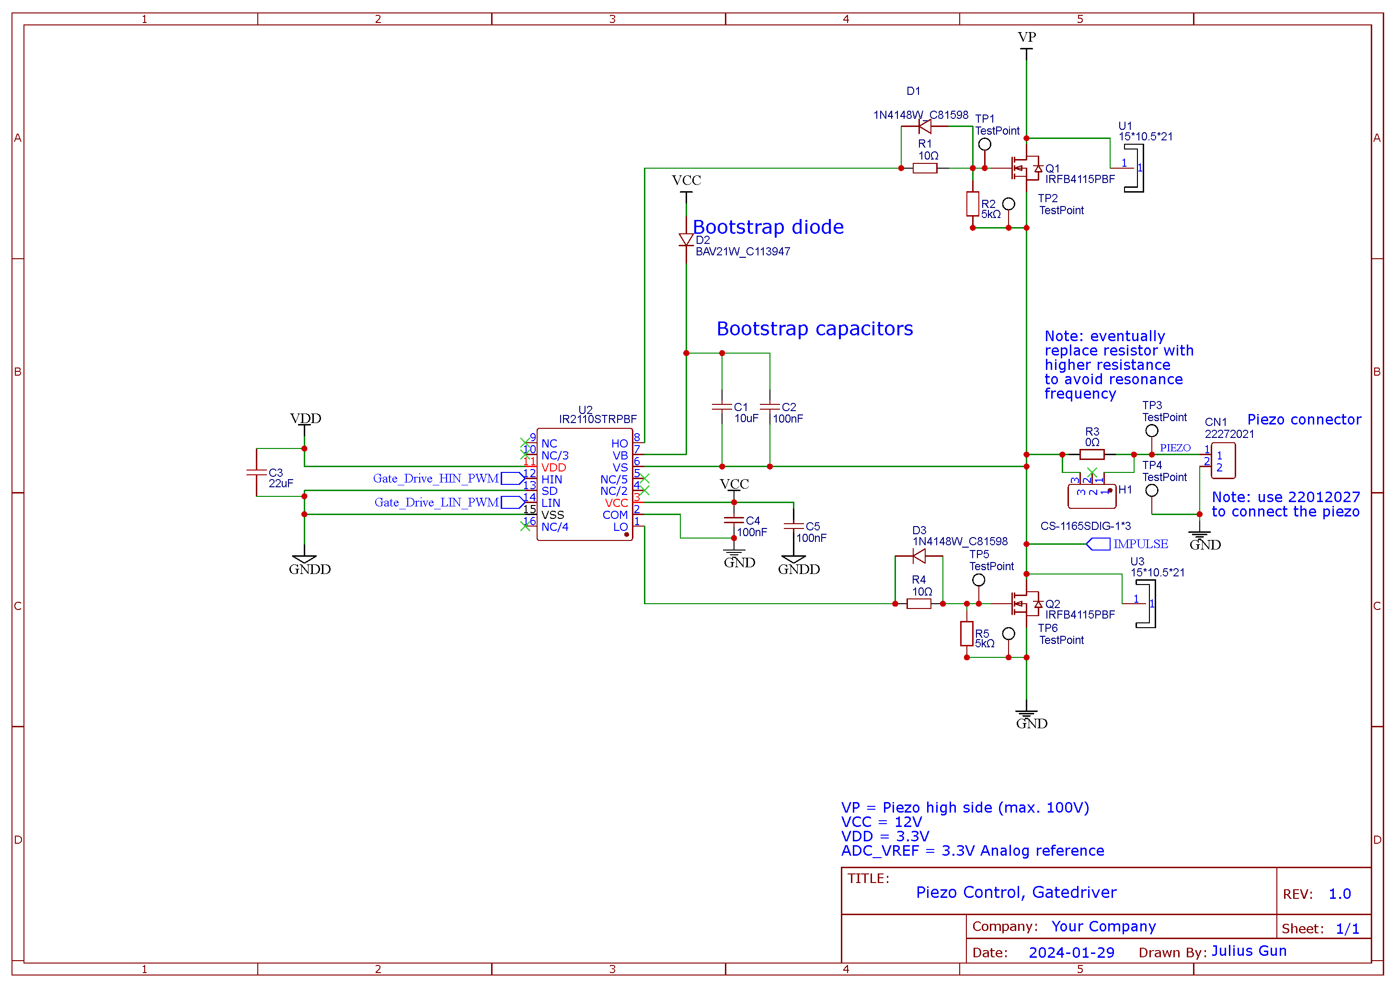
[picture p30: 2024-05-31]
PCB EasyEDA/PNG/Schematic/Piezo Control, Gatedriver.png

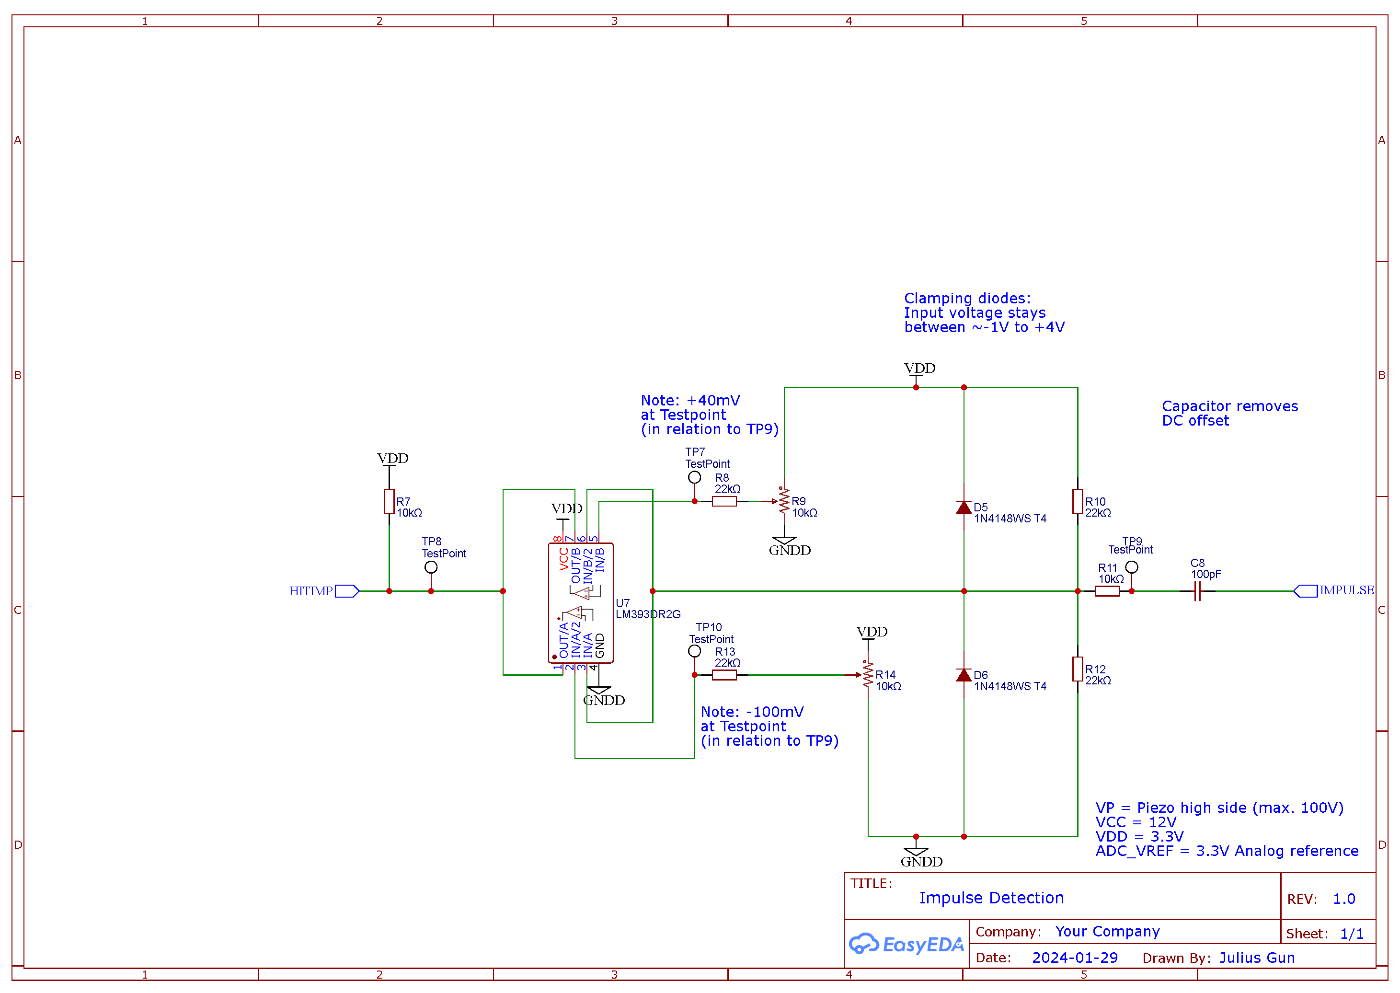
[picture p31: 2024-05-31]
PCB EasyEDA/PNG/Schematic/Impulse Detection.png

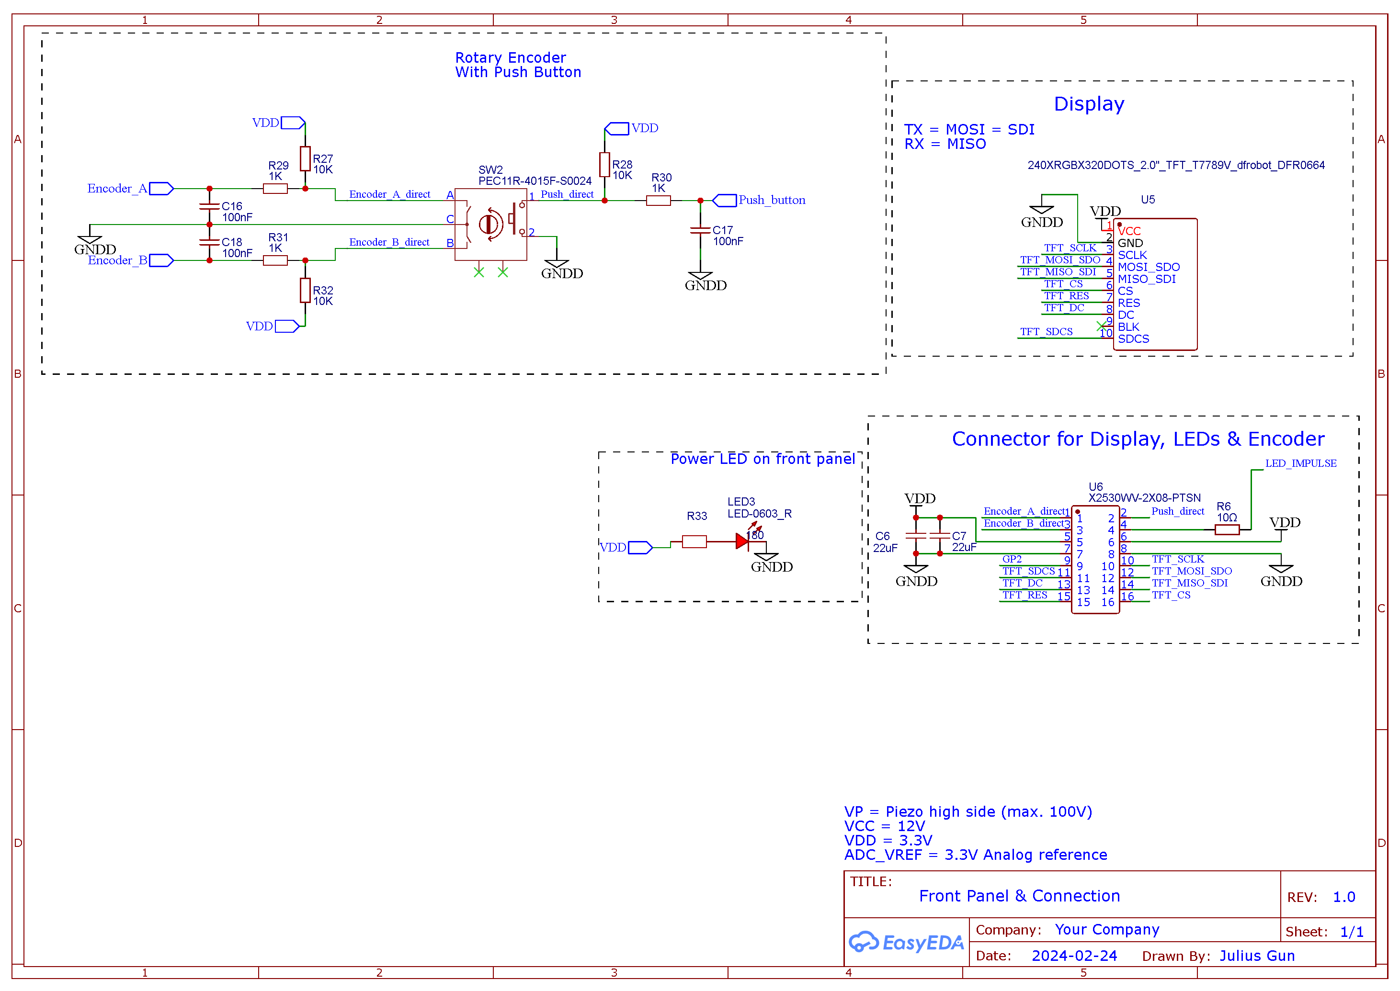
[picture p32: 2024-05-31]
PCB EasyEDA/PNG/Schematic/Encoder and LED's.png

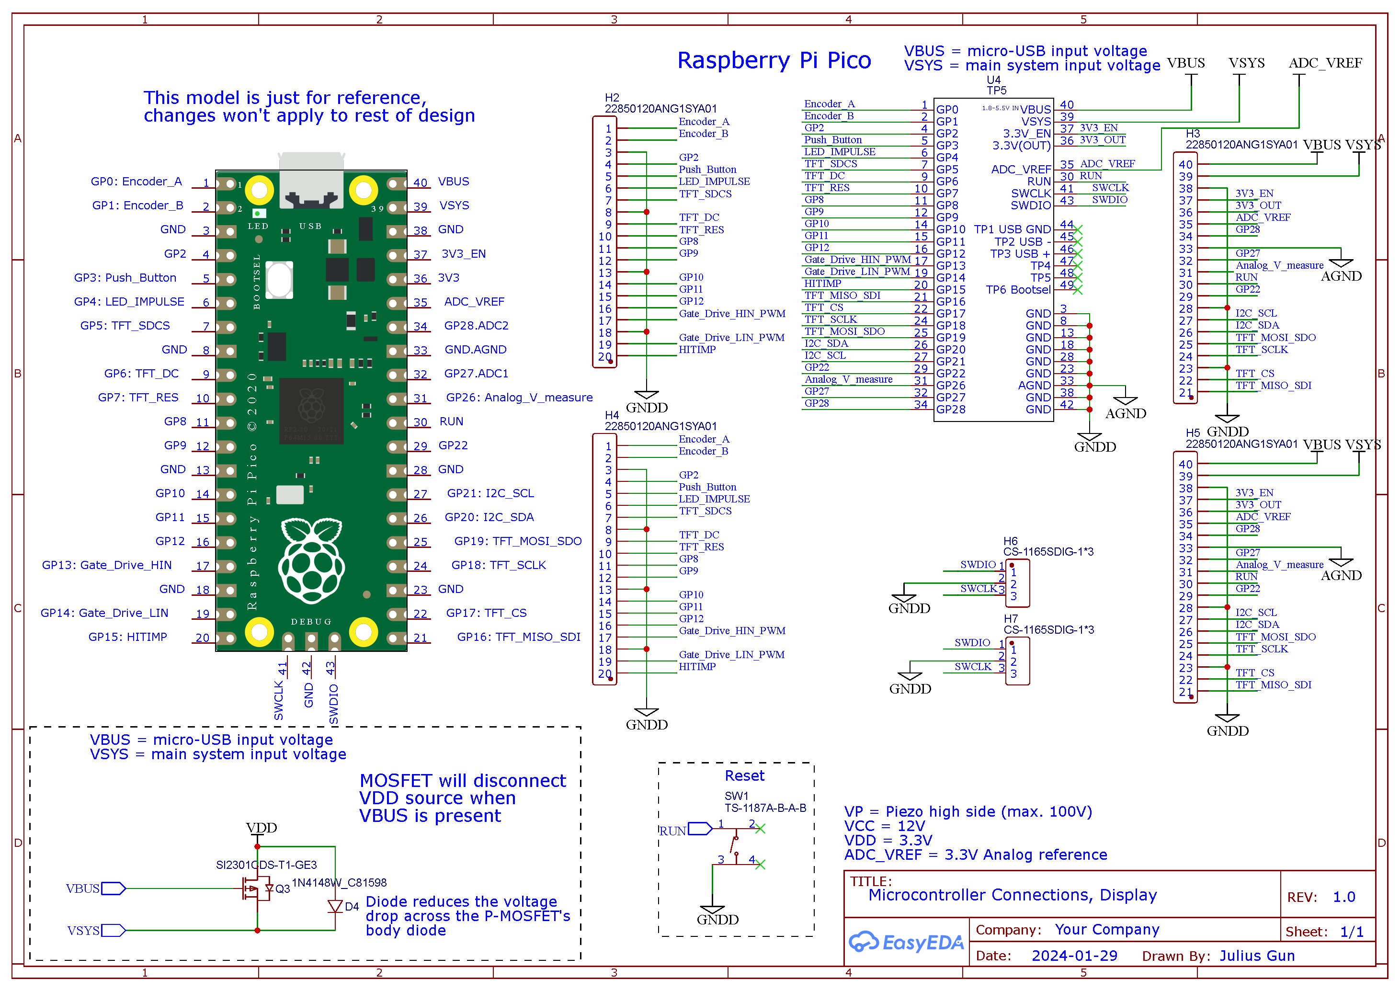
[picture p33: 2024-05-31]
PCB EasyEDA/PNG/Schematic/Microcontroller Connections.png

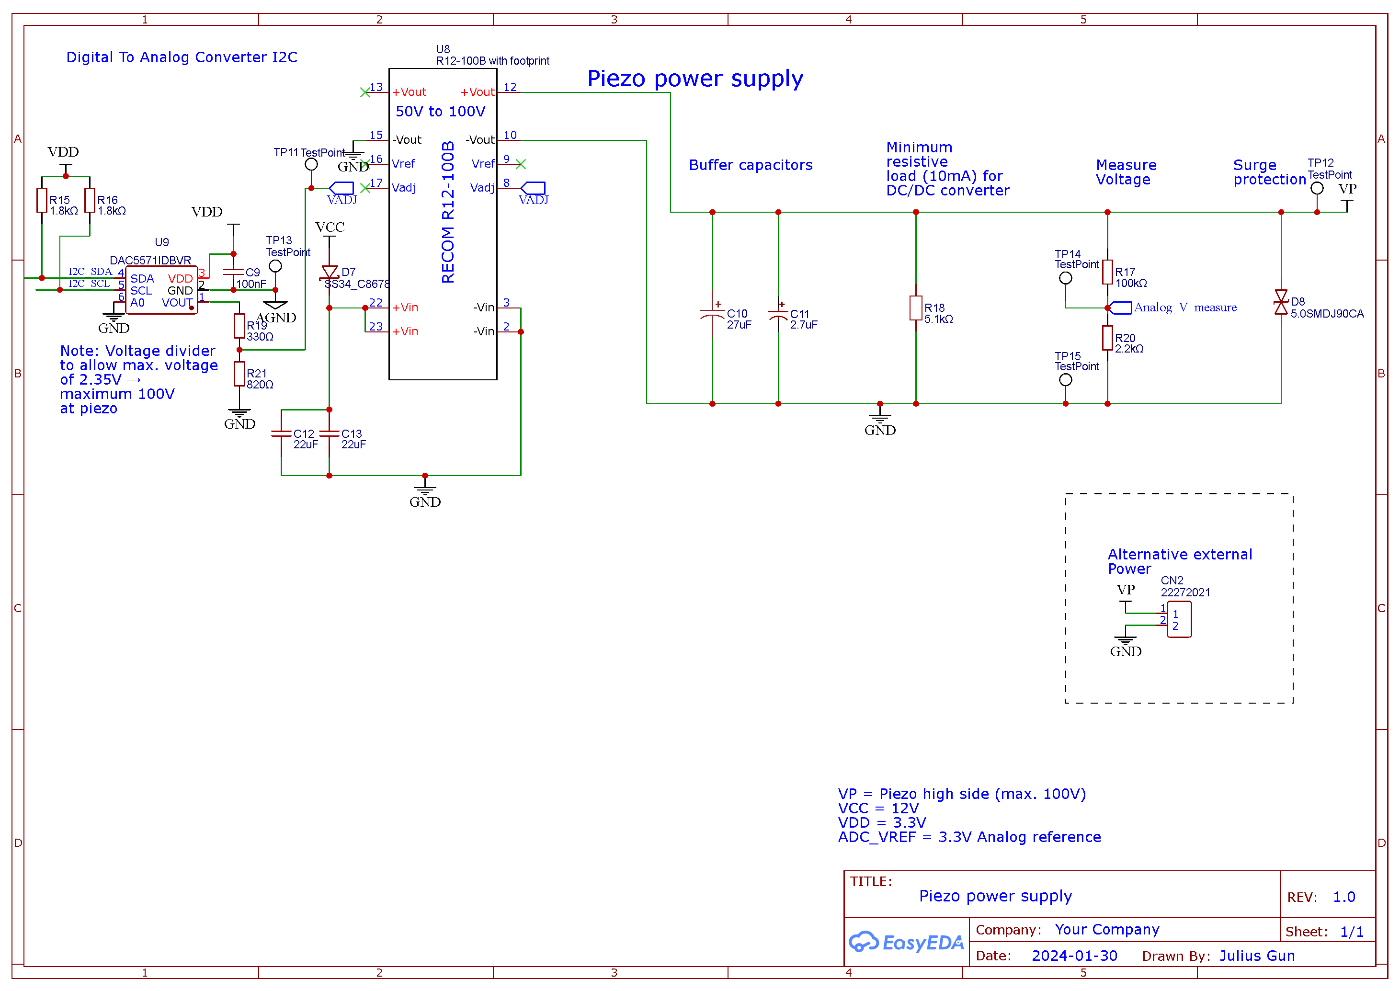
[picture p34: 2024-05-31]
PCB EasyEDA/PNG/Schematic/Power Supply Piezo 50V to 120V.png

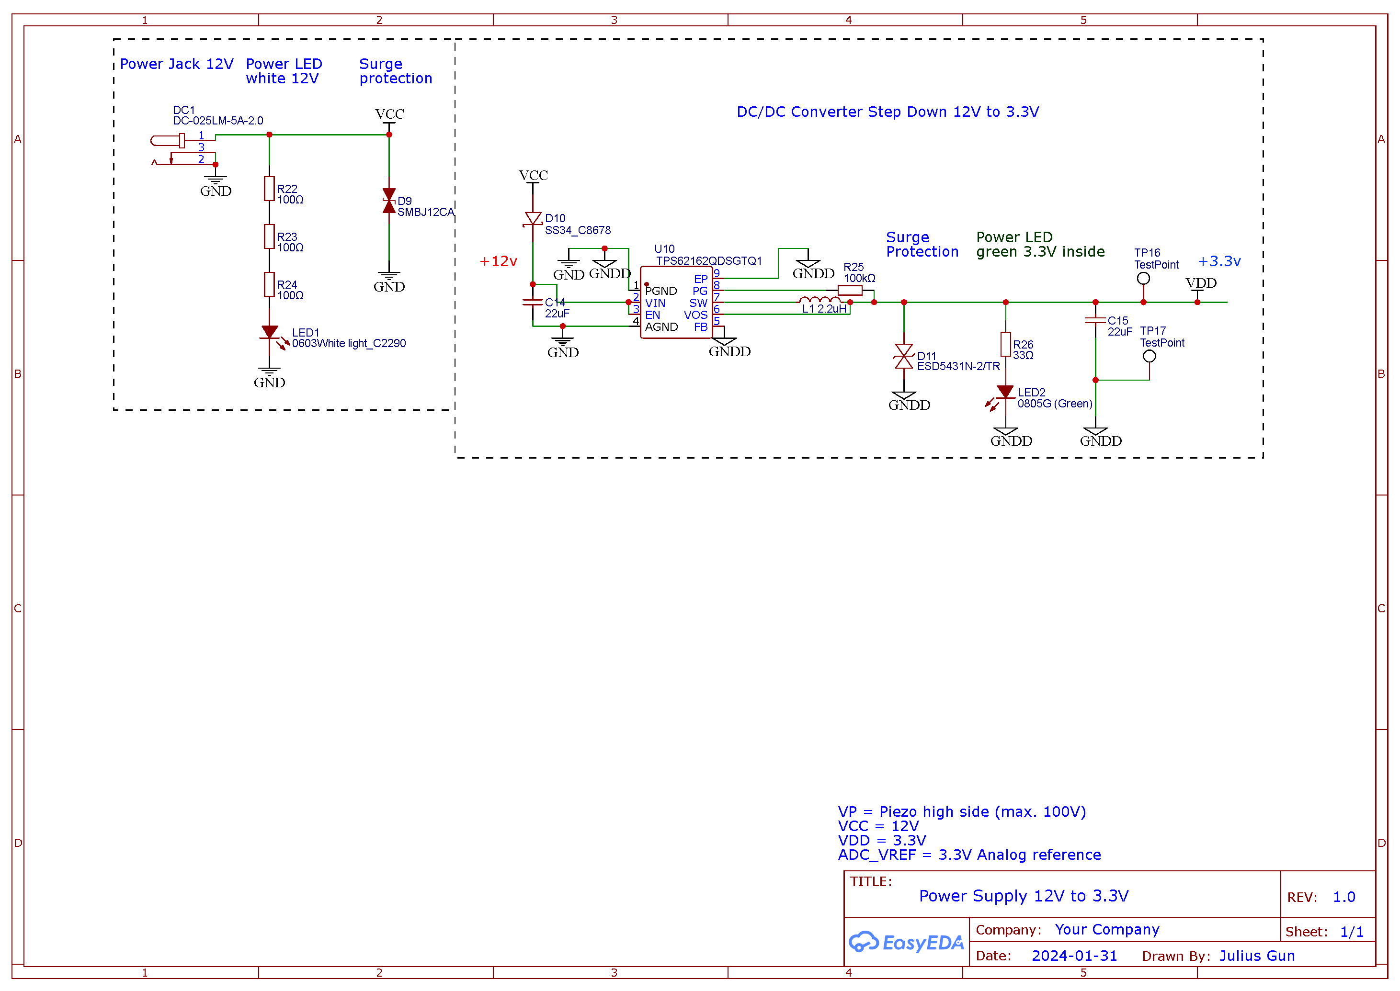
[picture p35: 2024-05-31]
PCB EasyEDA/PNG/Schematic/Power Supply 12V to 3.3V.png

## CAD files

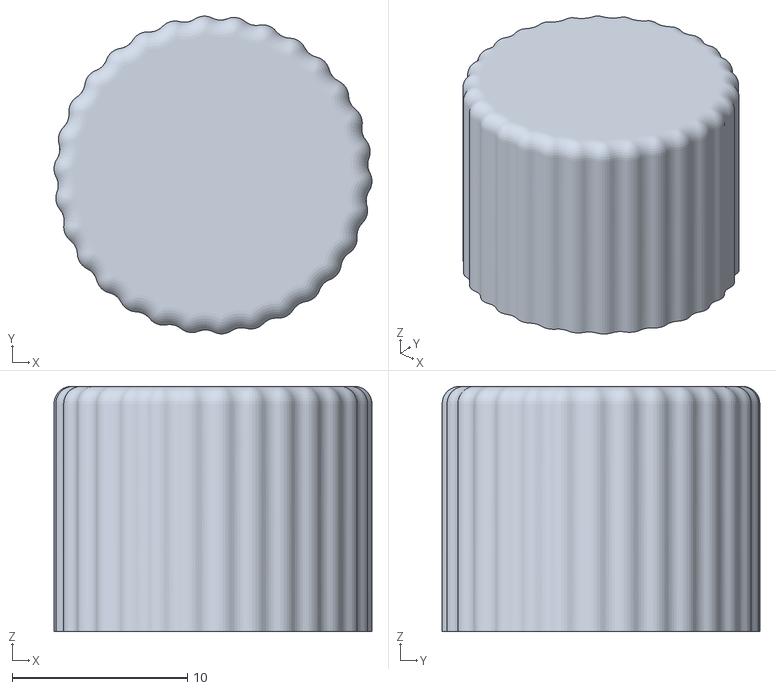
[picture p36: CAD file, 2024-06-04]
CAD Solidworks/STL files for 3D printing/piezopendulum Assembly - Noppen_V2-1.STL
18.1 x 18.1 x 14.0

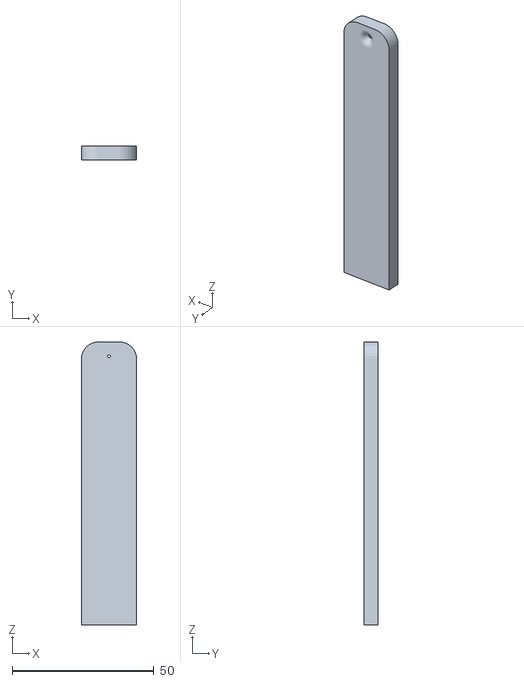
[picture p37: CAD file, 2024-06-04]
CAD Solidworks/STL files for 3D printing/piezopendulum Assembly - Wangenhalter 2^piezopendulum Assembly-1.STL
19.5 x 5.00 x 100.0

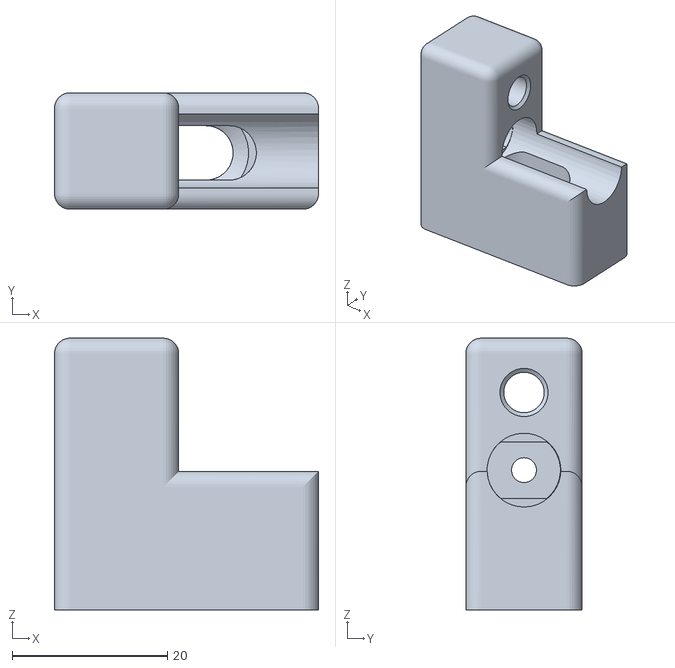
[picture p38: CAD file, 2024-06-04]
CAD Solidworks/STL files for 3D printing/piezopendulum Assembly - Piezohalter_V3-1.STL
34.0 x 15.0 x 35.0

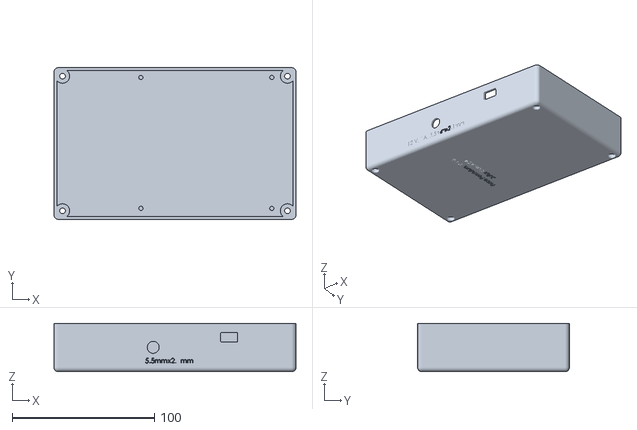
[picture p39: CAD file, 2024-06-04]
CAD Solidworks/STL files for 3D printing/piezopendulum Assembly - Undercarriage-1.STL
170.0 x 106.6 x 34.0

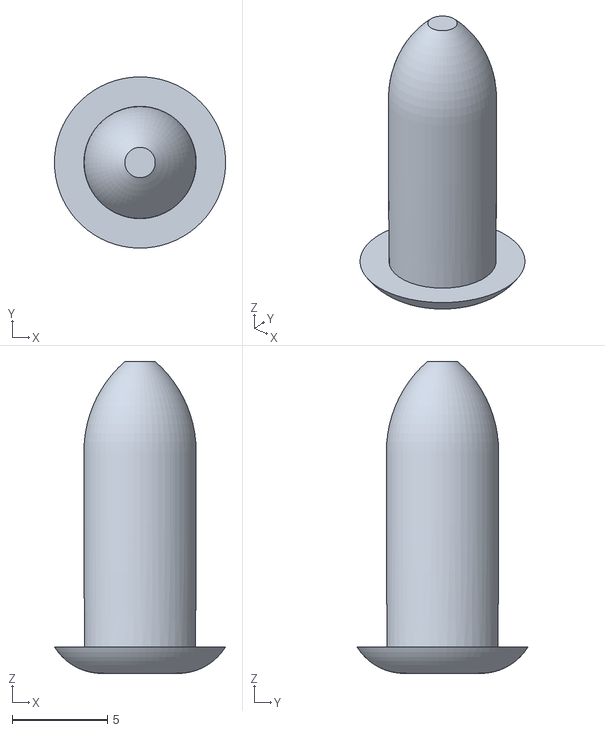
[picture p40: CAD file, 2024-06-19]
CAD Solidworks/STL files for 3D printing/Stuetznoppen.STL
9.00 x 9.00 x 16.4

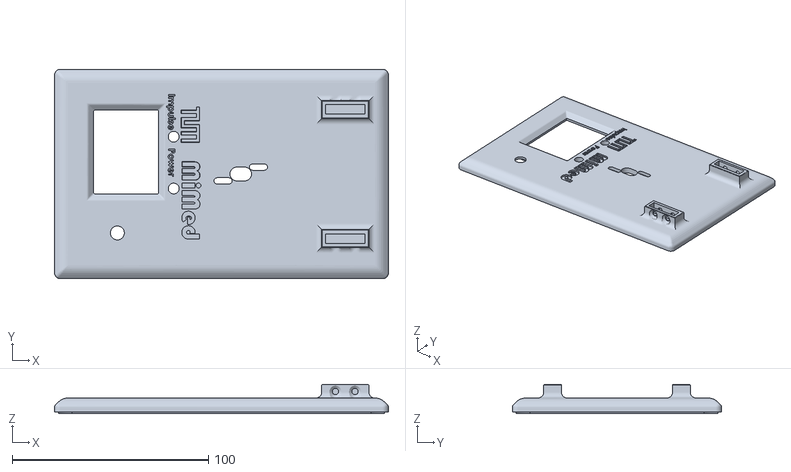
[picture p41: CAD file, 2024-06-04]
CAD Solidworks/STL files for 3D printing/Upperplate.STL
170.0 x 106.6 x 15.0

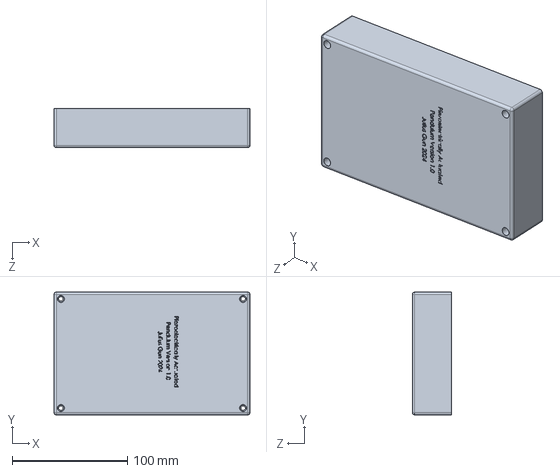
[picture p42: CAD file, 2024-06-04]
CAD Solidworks/Undercarriage.SLDPRT
170.0 x 106.6 x 34.0 mm

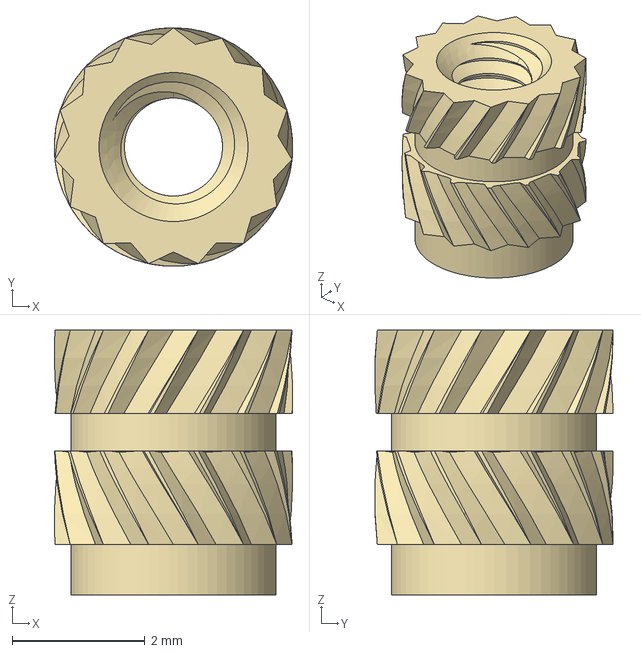
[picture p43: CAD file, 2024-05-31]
CAD Solidworks/Insert M2 D3.6 L4mm.stp
3.60 x 3.60 x 4.00 mm

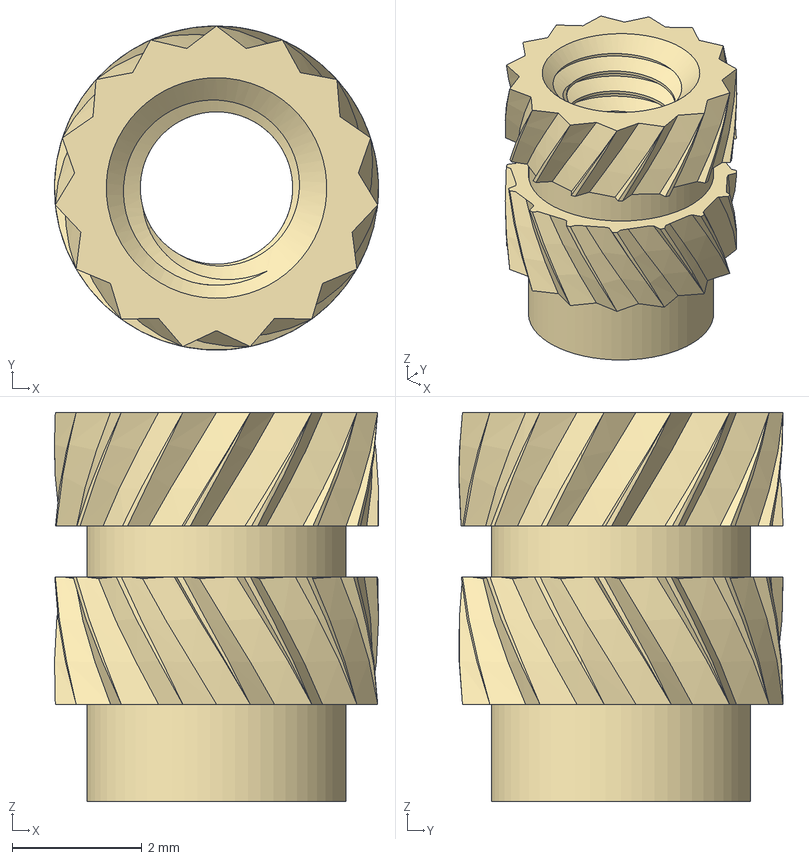
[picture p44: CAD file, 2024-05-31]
CAD Solidworks/Insert M3 D5 L5mm.stp
5.00 x 5.00 x 6.00 mm

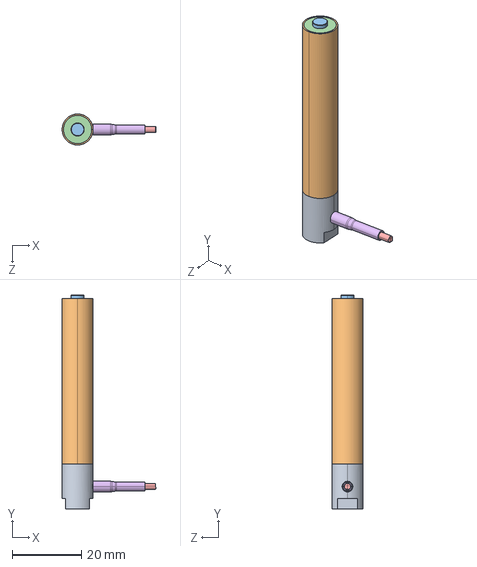
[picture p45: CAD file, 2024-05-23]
CAD Solidworks/P-820.30.STEP
27.2 x 62.0 x 9.00 mm

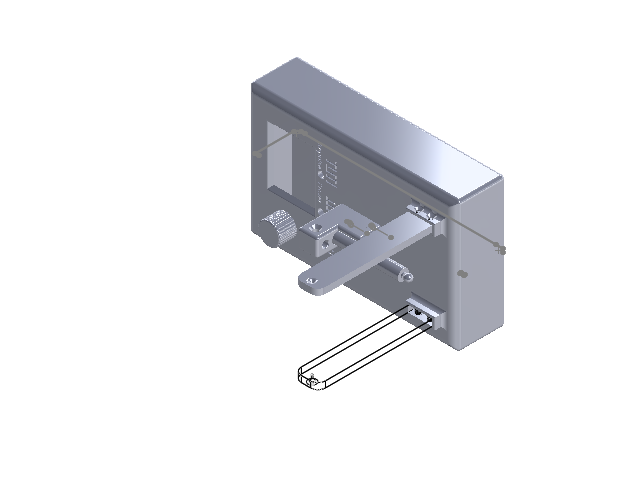
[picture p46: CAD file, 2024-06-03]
CAD Solidworks/piezopendulum Assembly.SLDASM
Upperplate
Noppen_V2
Piezohalter_V3
Wangenhalter 2^piezopendulum Assembly x 2
P-820.30.step
Undercarriage
Ball^piezopendulum Assembly
Insert M3 D5 L5mm.stp x 6
Insert M2 D3.6 L4mm.stp x 8

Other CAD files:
CAD Solidworks/STL files for 3D printing/piezopendulum Assembly - Wangenhalter 2^piezopendulum Assembly-4.STL
CAD Solidworks/Stuetznoppen.SLDPRT
CAD Solidworks/Upperplate.SLDPRT
CAD Solidworks/Piezohalter_V3.SLDPRT
CAD Solidworks/Noppen_V2.SLDPRT
CAD Solidworks/Drawings/piezopendulum Assembly.SLDDRW

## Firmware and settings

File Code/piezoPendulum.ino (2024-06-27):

/*!
 * @file piezoPendulum.ino
 * @brief This script is the main script to use the Piezo pendulum. The Raspberry Pi Pico RP2040 controls the display, reads the encoder and button inputs and controls the piezostack.
 * @n This demo supports at least Raspberry Pi Pico. Other boards are not tested.
 * @authors [Julius Gun, Jan Rodewald] //Jan Rodewald developed the first version V0.1
 * @version V1.2
 * @date 2024-06-14
 * https://github.com/julius-gun/piezopendulum
 */

// #include <Arduino.h>
// ------------------------------------------------------------------------------------------------------------------------------
// --- Read the libaries --------------------------------------------------------------------------------------------------------
// ------------------------------------------------------------------------------------------------------------------------------
#include "pico/stdlib.h"
#include "hardware/irq.h" // might be needed to access lower-level interrupt functions
#include "DFRobot_GDL.h"  // official Display Library
// #include <DAC7571.h>      // digital to analog converter library from https://github.com/jrj12591/DAC7571/
#include "src/DAC7571.h"
#include <SD.h>
#include <Wire.h>
#include <SPI.h>
#include <ButtonControl.h>
// ------------------------------------------------------------------------------------------------------------------------------
#define SYSTICK_FREQUENCY 133000000UL // 133MHz for RP2040
// ------------------------------------------------------------------------------------------------------------------------------
// --- Define the debug level ---------------------------------------------------------------------------------------------------
// RPI_PICO_Timer Timer; // Instantiate a timer object

// --- Initialize DAC5571 with default I2C address 0x4C → A0 connected to GND-------------------------------------------------------------------------------
// ------------------------------------------------------------------------------------------------------------------------------
DAC5571 dac;
#define I2C_SDA 20
#define I2C_SCL 21
#define I2C_PORT i2c0
const float VDD = 3.3; // Set the voltage that the DAC will run at
// Voltage regulation
float currentVoltage;
// ------------------------------------------------------------------------------------------------------------------------------
// --- Define fixed variables ---------------------------------------------------------------------------------------------------
// ------------------------------------------------------------------------------------------------------------------------------
// Display
#define TFT_DC 6
#define TFT_RST 7
#define TFT_MISO 16
#define TFT_CS 17
#define TFT_SCLK 18
#define TFT_MOSI 19
// Analog read Voltage
#define V_MEASURE 27
// Input pins definitions
#define ENCODER_A 1
#define ENCODER_B 0
ButtonControl PUSH_BUTTON(3);
#define HIT_IMPULSE 15 // Impulse detection
// Output pins definitions
#define LED_IMPULSE 4
#define LED_POWER 2
#define GATE_DRIVE_HIN 13
#define GATE_DRIVE_LIN 14
// Colors in RGB565 format
#define COLOR_BLACK 0x0000
#define COLOR_WHITE 0xFFFF
#define COLOR_TUM_BLUE 0x3396 // TUM Blue
#define COLOR_GREY 0x6CAF
#define COLOR_MIMED_YELLOW 0xFE60           // MiMed Yellow
#define FONT_COLOR_HEADLINES COLOR_TUM_BLUE // White
#define FONT_COLOR_READY_GREEN 0x07E0       // GREEN
#define FONT_COLOR_READY_RED 0xF800         // RED
#define COLOR_FILL_RECT COLOR_WHITE
// define positions
#define SCREEN_WIDTH 240  // 240
#define SCREEN_HEIGHT 320 // 320
#define TEXT_SIZE 3

// Text positions and dimensions (based on the selected font's characteristics)
#define CHARACTER_WIDTH (6 * TEXT_SIZE)
#define CHARACTER_HEIGHT (8 * TEXT_SIZE)

// Dynamic starting positions for text based on screen sections (as a fraction of SCREEN_HEIGHT)
#define STARTING_Y_READY (SCREEN_HEIGHT * .05)    // down from the top
#define STARTING_Y_HEAD (SCREEN_HEIGHT * 0.12)    // down from the top of the screen
#define STARTING_Y_MODES (SCREEN_HEIGHT * 0.25)   // down from the top
#define STARTING_Y_VARIABLE (SCREEN_HEIGHT * 0.8) // down from the top

#define STARTING_X 0
#define SCREEN_CLC_MODES_HEIGHT 160
#define SCREEN_CLC_READY_WIDTH 82
#define SCREEN_CLC_READY_HEIGHT 18

// define delays
#define TIME_DELAY_MAIN_LOOP 1
#define TIME_ENCODER_DELAY 500
#define TIME_READY_DELAY 1500
#define TIME_DELAY_INIT 500

// Initialize the display using hardware SPI communication
DFRobot_ST7789_240x320_HW_SPI screen(/*dc=*/TFT_DC, /*cs=*/TFT_CS, /*rst=*/TFT_RST);

// Miscellaneous variables
bool SERIAL_DEBUG = 0;  // CHANGE TO 0 in normal mode. Do you want to see the debug messages? 1 = yes, 0 = no
bool EXPERT_MODE = 0;   // CHANGE TO 0 in normal mode. Without it the delay finder function is disabled. 1 = yes, 0 = no
int menuItemIndex = 0;  // Use this variable to store the current index of the menu
bool currentStateClock; // Store the status of the clock pin (HIGH or LOW)
bool lastEncoderA;      // Store the PREVIOUS status of the clock pin (HIGH or LOW)
bool currentENCODER_B;
bool lastEncoderB;
bool buttonState = HIGH;  // Current state of the button
bool lastButtonState = 0; // Use this to store if the push button was pressed or not
unsigned int lastEncoderUpdateTime = 0;
unsigned int lastPushDebounceTime = 0;       // Last time the input pin was toggled
const unsigned int PUSH_DEBOUNCE_DELAY = 50; // Debounce delay in milliseconds

// ------------------------------------------------------------------------------------------------------------------------------
// --- Define menu items --------------------------------------------------------------------------------------------------------
// ------------------------------------------------------------------------------------------------------------------------------
// max Values
#define MAX_MENU_ITEMS 7 // Number of menu items
String menuOptionsShort[MAX_MENU_ITEMS] = {
    "All functions",
    "Push",
    "Catch",
    "Catch after 2",
    "Catch after 3",
    "Resonance",
    "Resonance        after 2"};

// once a function is selected, the long description is displayed instead of the short one, filling the lower side of the screen
String menuOptionsLong[MAX_MENU_ITEMS] = {
    "Cycle Through all Functions   Sequentially",
    "Push the     Pendulum Ball",
    "Push and     Catch after First Impulse",
    "Push and     Catch after      Second Impulse",
    "Push and     Catch after      Third Impulse",
    "Resonance:   Propels the Ball upon Immediate   Impulse Detection",
    "Resonance 2: Propels the Ball upon Second      Impulse Detection"};
// Resonance and catch after third

// for 64V
//  Timer delay for each menu item in microseconds
volatile unsigned int timerDelays[MAX_MENU_ITEMS] = {
    0, // Delay for "All functions"
    0, // Delay for "Push"
    14, // Delay for "Catch"
    5, // Delay for "Catch 2"
    5, // Delay for "Catch 3"
    0, // Delay for "Resonance"
    0  // Delay for "Resonance 2"
};

String headline = "Select action:";

String readyString[2] = {
    "execute",
    "ready"};
unsigned int readyState = 1;
unsigned int lastButtonPushed = 0;

// Piezo variables
volatile bool ballDetected = false;

// LED impulse variables
long ledOnTime = 0;

// ------------------------------------------------------------------------------------------------------------------------------
// --- Define functions ---------------------------------------------------------------------------------------------------------
// ------------------------------------------------------------------------------------------------------------------------------

// forward declarations for platformIO
bool checkButtonPressed(); // Button handling
int getEncoderPosition();
void inputMethods();
int changeMenuItem(int iChange);
void displayClearSection(int x, int y, int width, int height); // Display functions
void displayMenuText();
void displayReadyString();
void displayVoltage();
void chargePiezo(); // Piezofunctions
void waitForBallImpacts(int numberOfDetections);
void interruptBallDetected();
void ledImpulse();
void performPiezoAction(int piezoSelect);
void executePushAction();
void executePushAndCatchAction(int bounceCount);
void executeResonanceAction(int bounceCount);
void handleSerialInput();
void dischargePiezo(uint32_t timeToDischargePiezoMicroseconds);
void chargeBootstrapCapacitor(uint32_t timeToChargeCapacitorMicroseconds);
float readVoltagePiezo(); // voltage
void setPiezoActuatorVoltage(float voltage);
void setupI2CDAC(); // Setup helper functions
void setupGatedriver();
void setupEncoder();
void setupInterrupts();
void setupScreen();

// ------------------------------------------------------------------------------------------------------------------------------
// ----Functions------------------------
void enablePiezoInterrupt() // Enable the interrupts for the ball detection pin

{
  attachInterrupt(digitalPinToInterrupt(HIT_IMPULSE), interruptBallDetected, RISING);
}

// void disablePiezoInterrupt() // Disable the interrupts for the ball detection pin → rather not use this function because it takes too long to reenable the interrupt
// {
//   // Disable the interrupts for the ball detection pin
//   detachInterrupt(digitalPinToInterrupt(HIT_IMPULSE));
// }

// unsigned long lastDetectionTime = 0;                // Tracks the time since the last detection
volatile unsigned int lastImpulseDebounceTime = 0; // Timestamp of the last time the ISR was triggered

// Interrupt Service Routine (ISR) for the ball detected pin
const uint16_t IMPULSE_DEBOUNCE_DELAY_CATCH = 4; // Debounce delay for resonance in milliseconds

void interruptBallDetected()
{
  // Check if enough time has passed since the last detected interrupt (debouncing)
  if ((millis() - lastImpulseDebounceTime) > IMPULSE_DEBOUNCE_DELAY_CATCH)
  {
    ballDetected = true;
    digitalWrite(LED_IMPULSE, HIGH); // Turn on the LED
    ledOnTime = millis();            // Set the time the LED was turned on
    // Update the lastImpulseDebounceTime to the current time
    lastImpulseDebounceTime = millis();
  }
}

void delayAndDoStuff(int timeDelayMilliseconds)
{
  unsigned int currentTime = millis();
  while (millis() - currentTime < timeDelayMilliseconds)
  {
    ledImpulse();
  }
}

bool longPressActive = false;
/**
 * Checks if the button is pressed and returns a value indicating the button state, with debouncing.
 *
 * @return true if the button is pressed, false otherwise.
 */
int LONG_PRESS_DELAY = 1000;
bool checkButtonPressed()
{
  if (PUSH_BUTTON.longClick())
  {
    int commandToExecute = menuItemIndex + 1;
    if (commandToExecute > 2 && commandToExecute < 6)
    {
      if (PUSH_BUTTON.getLongClickTime() > LONG_PRESS_DELAY) // press button for 1s to start delay function
      {
        longPressActive = true;
        return false;
      }
      else
      {
        longPressActive = false;
        return true;
      }
    }
    else
    {
      longPressActive = false;
      return true;
    }
  }
  else
  {
    return false;
  }
}

// variables for the encoder
const int ENCODER_COUNTER_CLOCKWISE = -1; // ↺ Counter clockwise rotation
const int ENCODER_NO_CHANGE = 0;
const int ENCODER_CLOCKWISE = 1; // ↻ Clockwise rotation

// Function to check if encoder has changed
int getEncoderPosition()
{
  int changeValue = ENCODER_NO_CHANGE; // Default to no change
  unsigned long currentEncoderTime = millis();

  // Read the current state of the encoder pins
  int currentEncoderA = digitalRead(ENCODER_A);
  int currentEncoderB = digitalRead(ENCODER_B);

  // Check if there has been any change in the state of the encoder pins
  if (lastEncoderA != currentEncoderA || lastEncoderB != currentEncoderB)
  {
    if (currentEncoderTime > (lastEncoderUpdateTime + TIME_ENCODER_DELAY))
    {
      // Check the transition of state to determine direction
      if (((currentEncoderA == 1 && currentEncoderB == 0) && (lastEncoderA == 0 && lastEncoderB == 0)) || ((currentEncoderA == 1 && currentEncoderB == 1) && (lastEncoderA == 1 && lastEncoderB == 0)) || ((currentEncoderA == 0 && currentEncoderB == 1) && (lastEncoderA == 1 && lastEncoderB == 1)) || ((currentEncoderA == 0 && currentEncoderB == 0) && (lastEncoderA == 0 && lastEncoderB == 1)))
      {
        changeValue = ENCODER_COUNTER_CLOCKWISE; // ↺ Counter clockwise rotation
      }
      else if (((currentEncoderA == 0 && currentEncoderB == 1) && (lastEncoderA == 0 && lastEncoderB == 0)) || ((currentEncoderA == 1 && currentEncoderB == 1) && (lastEncoderA == 0 && lastEncoderB == 1)) || ((currentEncoderA == 1 && currentEncoderB == 0) && (lastEncoderA == 1 && lastEncoderB == 1)) || ((currentEncoderA == 0 && currentEncoderB == 0) && (lastEncoderA == 1 && lastEncoderB == 0)))
      {
        changeValue = ENCODER_CLOCKWISE; // ↻ Clockwise rotation
      }

      // If a valid item change has occurred, update the time
      lastEncoderUpdateTime = millis();
    }
    lastEncoderA = currentEncoderA;
    lastEncoderB = currentEncoderB;
  }

  return changeValue; // Return the change in menu item (-1, 0, 1)
}

int changeMenuItem(int step)
{
  menuItemIndex += step;
  if (menuItemIndex >= MAX_MENU_ITEMS)
  {
    menuItemIndex = MAX_MENU_ITEMS - 1;
  }
  else if (menuItemIndex < 0)
  {
    menuItemIndex = 0;
  }
  return menuItemIndex; // Return the updated menu item index.
}

void inputMethods()
{
  // Check for encoder rotation
  int encoderChange = getEncoderPosition();
  if (encoderChange != ENCODER_NO_CHANGE)
  {
    changeMenuItem(encoderChange);
    displayMenuText();
  }

  // Check for button press
  int newButtonPushed = millis();
  if (newButtonPushed > lastButtonPushed + TIME_READY_DELAY && readyState != 1)
  {
    readyState = 1;
    displayReadyString();
  }
  else if (checkButtonPressed() == 1)
  {
    if (newButtonPushed > lastButtonPushed + TIME_READY_DELAY)
    {
      lastButtonPushed = newButtonPushed;
      readyState = 0;
      displayReadyString();
    }
  }
  // Execute the selected action
  if (readyState == 0) // Condition met when execute button clicked
  {
    menuSelectAction();
  }
  if (longPressActive && EXPERT_MODE)
  {
    delayTimeHelper();
  }
}

void menuSelectAction()
{
  int commandToExecute = menuItemIndex + 1; // Menu item index matches performPiezoAction case
  if (SERIAL_DEBUG)
  {
    Serial.print("Piezo command selected: ");
    Serial.println(menuOptionsShort[menuItemIndex]); // Print the string
  }
  delayAndDoStuff(500);                 // Delay so that the push button does not cause the ball to not be in the right position
  ballDetected = false;                 // if the push button caused the interrupt to be triggered, falsify it again
  performPiezoAction(commandToExecute); // menuItemIndex starts at 0, and case 1 is "Push"
  readyState = 1;                       // Reset the ready flag to prevent repeated command execution without button presses
  displayMenuText();                    // Update the display to show the Menu text
  displayReadyString();                 // Update the display to show the change in state
  displayVoltage();
}

// Modular helper function implementations
void displayClearSection(int x, int y, int width, int height)
{
  screen.fillRect(x, y, width, height, COLOR_FILL_RECT); // Clear the designated screen section
}

void displayMenuText()
{
  // Calculate the number of items to display before and after the selected item.
  const int itemsBeforeAfter = 2;

  // Clear the menu area before displaying the new text
  displayClearSection(STARTING_X, STARTING_Y_MODES, screen.width(), SCREEN_CLC_MODES_HEIGHT);

  // Display 5 menu options at a time: 2 before, 1 current, and 2 after
  for (int offset = -itemsBeforeAfter; offset <= itemsBeforeAfter; ++offset)
  {
    int menuIndex = menuItemIndex + offset;

    // Skip if the menuIndex is out of the array bounds
    if (menuIndex < 0 || menuIndex >= MAX_MENU_ITEMS)
    {
      continue;
    }

    // Calculate the Y position for each item; adjust it based on your screen's layout
    int yPos = STARTING_Y_MODES + (CHARACTER_HEIGHT + 2) * (offset + itemsBeforeAfter);

    // Set cursor position
    screen.setCursor(STARTING_X, yPos);

    // Set the text color: highlight the current menu item, otherwise use the default color
    uint16_t color = (offset == 0) ? COLOR_MIMED_YELLOW : FONT_COLOR_HEADLINES;
    screen.setTextColor(color);

    // Set the text size for uniformity
    screen.setTextSize(TEXT_SIZE);

    // Print the menu index and option
    screen.println(String(menuIndex + 1) + " - " + menuOptionsShort[menuIndex]);
  }

  ledImpulse();
}

// instead of displayMenuText the full function name is displayed for comprehension
void displayCurrentFunctionDescription()
{
  displayClearSection(STARTING_X, STARTING_Y_MODES, screen.width(), SCREEN_CLC_MODES_HEIGHT);
  screen.setCursor(STARTING_X, STARTING_Y_MODES);
  screen.setTextColor(COLOR_MIMED_YELLOW);
  screen.setTextSize(TEXT_SIZE);
  screen.println(String(menuItemIndex + 1) + " - " + menuOptionsLong[menuItemIndex]);
  ledImpulse();
}

// instead of displayMenuText the full function name is displayed for comprehension
void displayDelayHelperText()
{
  displayClearSection(STARTING_X, 200, screen.width(), 40);
  screen.setCursor(STARTING_X, 220);
  screen.setTextColor(COLOR_MIMED_YELLOW);
  screen.setTextSize(TEXT_SIZE);
  screen.println("Set delay time");
  ledImpulse();
}

void displayReadyString()
{
  ledImpulse();
  // Calculate the dimensions needed for the text based on text length and size
  int textLength = readyString[readyState].length();
  int textWidth = CHARACTER_WIDTH * textLength * 1.4; // Width of entire text string
  int textHeight = CHARACTER_HEIGHT;                  // Height of text string

  // Calculate starting X so the text is horizontally centered
  int textX = STARTING_X;
  int textY = STARTING_Y_READY - (textHeight / 2); // Adjust Y so the text is vertically centered

  // Clear the rectangle area where the ready string will be displayed
  displayClearSection(textX, textY, textWidth, textHeight);

  // Set the cursor to the calculated starting position for the ready string
  screen.setCursor(textX, textY);
  // Set the text color depending on the state of readyState
  if (readyState == 0)
  {
    screen.setTextColor(FONT_COLOR_READY_RED);
  }
  else
  {
    screen.setTextColor(FONT_COLOR_READY_GREEN);
  }
  // Set the text size and print the string
  screen.setTextSize(TEXT_SIZE);
  screen.println(readyString[readyState]);
  if (readyState == 0)
  {
    if (SERIAL_DEBUG)
    {
      displayTimeMicroseconds();
    }
  }
  else
  {
    displayVoltage();
  }
}

void displayHeader(String headerText)
{
  displayClearSection(STARTING_X, STARTING_Y_HEAD, screen.width(), CHARACTER_HEIGHT);
  screen.setCursor(STARTING_X, STARTING_Y_HEAD);
  screen.setTextColor(COLOR_BLACK);
  screen.setTextSize(TEXT_SIZE);
  screen.println(headerText);
}

void displayVoltage()
{
  currentVoltage = (int)readVoltagePiezo();
  int textWidth = 300; // Width of entire text string
  int textX = 245;
  int textY = STARTING_Y_READY - (CHARACTER_HEIGHT / 2);
  screen.setCursor(textX, STARTING_Y_READY - (CHARACTER_HEIGHT / 2));
  screen.setTextColor(COLOR_TUM_BLUE);
  screen.setTextSize(TEXT_SIZE);
  // Clear the rectangle area where the ready string will be displayed
  displayClearSection(140, textY, textWidth, CHARACTER_HEIGHT);
  screen.print(currentVoltage, 0);
  screen.print("V");
}

void displayTimeMicroseconds()
{
  int textX = 140;
  int textY = STARTING_Y_READY - (CHARACTER_HEIGHT / 2);
  displayClearSection(textX, textY, 200, CHARACTER_HEIGHT);
  int charHeight = CHARACTER_HEIGHT;
  screen.setTextSize(TEXT_SIZE - 1);
  screen.setCursor(textX, STARTING_Y_READY - (charHeight / 2));
  screen.setTextColor(COLOR_TUM_BLUE);
  int timeDelay = timerDelays[menuItemIndex];
  screen.print("delay: ");
  screen.print(timeDelay);
  screen.print("us");
}

// --- Piezo functions ------------------------------------------------------------------------------------------

/*in a bootstrap configuration, the low side MOSFET (Q2) is turned on to discharge
the piezo and charge the bootstrap capacitor, so that the piezo can be charged
again. The bootstrap capacitor looses its charge over time, so it needs to be
recharged before switching the high side MOSFET (Q1)*/

void chargeBootstrapCapacitorFast()
{
  delayMicroseconds(1); // → never comment this, this is shoot through delay time
  digitalWrite(GATE_DRIVE_LIN, HIGH);
  digitalWrite(GATE_DRIVE_LIN, LOW);
}
void chargeBootstrapCapacitor(uint32_t timeToChargeCapacitorMicroseconds)
{
  delayMicroseconds(1); // → never comment this, this is shoot through delay time
  digitalWrite(GATE_DRIVE_LIN, HIGH);
  // delayMicroseconds(timeToChargeCapacitorMicroseconds);
  delayMicroseconds(30);
  digitalWrite(GATE_DRIVE_LIN, LOW);
  delayMicroseconds(10);
}

/**
 * @brief Turns the piezo actuator instantly on, using the gatedriver.
 */
void chargePiezo()
{
  digitalWrite(GATE_DRIVE_HIN, HIGH); // SHOOT: Turn on higher side MOSFET (Q1)
  delayMicroseconds(100);             // todo: optimize time
  digitalWrite(GATE_DRIVE_HIN, LOW);  // Turn off higher side MOSFET (Q1)
  delay(25);                          // now: 50ms todo: how long does it take to charge the capacitor? + 10%
}

unsigned int DISCHARGE_PIEZO_TIME = 30; // this time needs to be adjusted according to the piezo
void dischargePiezo(uint32_t timeToDischargePiezoMicroseconds)
{
  delayMicroseconds(1); // → never comment this, this is shoot through delay time
  delayMicroseconds(timeToDischargePiezoMicroseconds);
  digitalWrite(GATE_DRIVE_LIN, HIGH);
  delayMicroseconds(DISCHARGE_PIEZO_TIME);
  digitalWrite(GATE_DRIVE_LIN, LOW);
}
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
void loop()
{
  inputMethods();
  ledImpulse();
  // testTimes();
}

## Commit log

2024-05-23 PCB piezopendulum design 1.1,
    fixed wrong diode D2
    small errors fixed
2024-05-23 CAD files added
    [Assem1 - Noppen_V2-1.STL, Assem1 - Piezohalter_V3-1.STL, Assem1 - Undercarriage-1.STL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]
2024-05-31 final version Thesis
    final version Thesis, CAD still has error
    [Insert M2 D3.6 L4mm.stp, Insert M3 D5 L5mm.stp, Piezohalter_V3.SLDPRT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]
2024-06-03 CAD update, now centered planes
    [Piezohalter_V3.SLDPRT, piezopendulum Assembly.SLDASM, piezopendulum Assembly.SLDDRW]
2024-06-04 CAD design improved, ribs in top part; rib sketch in undercarriage prepared
    [Assem1 - Noppen_V2-1.STL, Assem1 - Piezohalter_V3-1.STL, Assem1 - Undercarriage-1.STL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]
2024-06-18 new supporting element :Stütznoppen) to keep pendulum level
    [Stuetznoppen.SLDPRT, Stuetznoppen.STL]
2024-06-19 improved Stuetznoppen so it holds better in place
    [Stuetznoppen.SLDPRT, Stuetznoppen.STL]
